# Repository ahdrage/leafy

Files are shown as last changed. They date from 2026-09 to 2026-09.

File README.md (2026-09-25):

# Leafy — DIY Wi-Fi Climate Controller for Nissan Leaf

**A DIY Nissan Leaf climate On/Off controller for home Wi-Fi.**

Leafy combines a custom ESP32-C3 board, a local web page and a printable enclosure. It requests climate operation over CAN; it does not carry or switch heater power. The intended profile is the **2013–2015 Leaf EV-CAN implementation**, subject to checking the actual vehicle and TCU configuration.

**Status: untested hardware prototype, Rev G.5 prepared for manufacture.** PCB production files and final component placement have been reviewed. Firmware builds and host tests pass, but no assembled Leafy has yet demonstrated heater control in a car. CAN transmission is disabled by default.

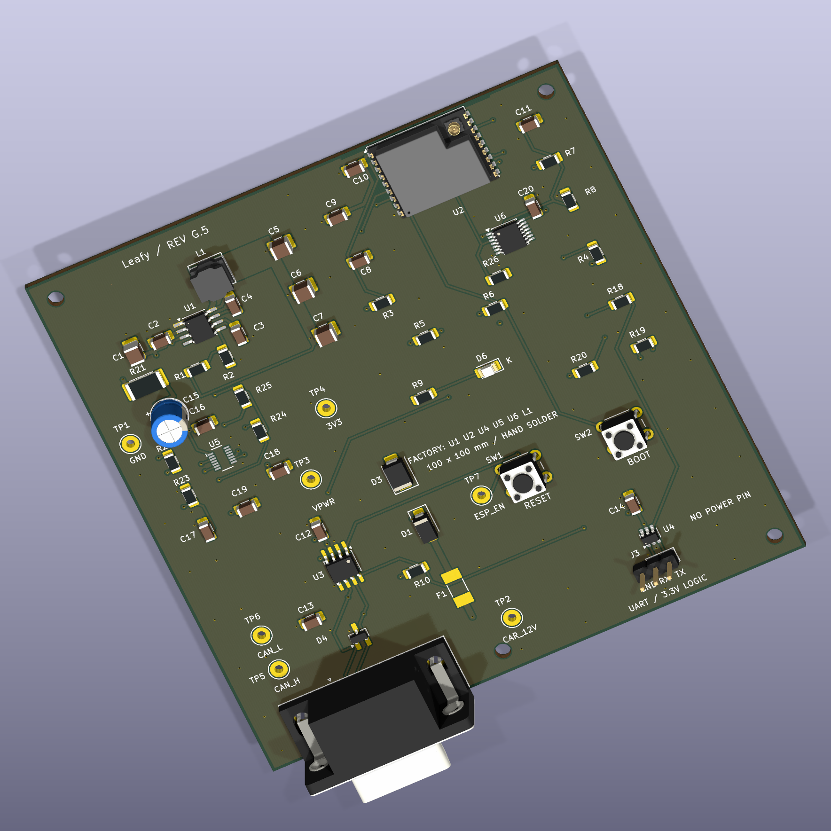
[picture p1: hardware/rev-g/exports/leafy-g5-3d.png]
Leafy G.5 PCB render


## Start here

| Goal | Documentation |
| --- | --- |
| Understand the project | [How it works](docs/OVERVIEW.md) |
| Build one | [Build guide](docs/BUILD-GUIDE.md) |
| Understand the decisions | [Development history](docs/DEVELOPMENT-HISTORY.md) |
| Inspect the current circuit | [G.5 design](hardware/rev-g/README.md), [schematic PDF](hardware/rev-g/exports/schematic.pdf), [KiCad project](hardware/rev-g/leaf-heat-v7.kicad_pro) |
| Buy components | [Parts and costs](docs/PARTS-AND-COSTS.md) |
| Order the PCB / partial assembly | [G.5 order guide](hardware/rev-g/ORDER-G5.md) |
| Build or test firmware | [Firmware instructions](firmware/leaf-heat/README.md) |
| Print the case | [Blender and STL files](enclosure/rev-g-v2/README.md) |
| Check the evidence | [Validation status](docs/VALIDATION.md) |

## Deliberately small scope

- **Heat on / Heat off** from a browser on the same home network.
- Wi-Fi only, external antenna, no SIM, subscription or cloud service.
- One CAN channel and the specified Nissan OVMS cable pinout.
- A 100 × 100 mm, four-layer PCB with generous hand-solder spacing.
- Factory assembly of **U1/U2/U4/U5/U6/L1**; **49 other components per board** are hand-soldered and the antenna plugs in.
- Independent low-battery cutoff, input damping and protected power/CAN interfaces.

Normal operation keeps Wi-Fi associated and retries after outages. **Battery protection cuts the board's power when voltage is too low**, so it becomes unreachable until the supply recovers. Availability also depends on the router and signal. Parked current and real-world reliability still need measurement.

The commands request the vehicle's climate function, not a particular heater element or temperature setpoint. The page reports requests, not independently verified heating.

## Thanks to OVMS

Leafy was inspired by the [Open Vehicle Monitoring System (OVMS)](https://www.openvehicles.com/). Its narrow Leaf wake-up and climate-command sequence is **derived from the OVMS Nissan Leaf implementation**, pinned to revision `85074a0ae7a983b308c6e2e081185492527ee073`.

Thank you to the OVMS authors and contributors for making this work available. The original MIT notice is retained in [OVMS-NOTICE.txt](firmware/leaf-heat/OVMS-NOTICE.txt). [Credits and provenance](CREDITS.md) explain the relationship and other sources. Leafy is an independent prototype, with no claimed OVMS or Nissan endorsement.

## Repository map

- `hardware/rev-g/`: current G.5 CAD, BOMs, manufacturing files, reviews and audit tools. The internal filename `leaf-heat-v7` is intentional.
- `firmware/leaf-heat/`: ESP-IDF firmware, settings template and 25 host tests.
- `enclosure/rev-g-v2/`: Blender source, STLs, renders and G.5 compatibility. Case renders retain their G.3 artwork provenance.
- `docs/`: project history, construction, costs, validation and publication notes.
- Earlier revisions and research: development history, **not current manufacturing instructions**. Always use matching G.5 files.

The public snapshot excludes personal supplier records, credentials, configured firmware images, downloaded toolchains and unrelated projects. Originals remain local. See [publication scope](docs/PUBLICATION.md).

## Licences

See [LICENSE.md](LICENSE.md) for the project licence boundaries and retained third-party notices.

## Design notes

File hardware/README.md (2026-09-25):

> **Historical development record.** The current release is [Leafy G.5](../README.md). Use this file for context, not current ordering or wiring instructions.

> **Rev A archive:** current manufacturing files are [Leafy Rev G.5](rev-g/README.md). All earlier revisions are preserved. The specifications below describe the obsolete two-layer Rev A.

# Leaf Heat — custom Wi-Fi board, Rev A

**Engineering prototype, not released for manufacture or vehicle installation.**

The native KiCad 10 project is [leaf-heat-v1.kicad_pro](leaf-heat-v1.kicad_pro). It contains an editable schematic and a fully routed, two-layer 65 × 50 mm PCB. There are 47 populated components and three mounting holes. The module antenna and the car connector extend beyond the PCB outline.

The design is for a small box with a local Wi-Fi page containing **Heat on** and **Heat off**. This delivery contains the hardware design, not working firmware. Home Wi-Fi coverage was confirmed by the owner. The earlier Waveshare development-board plan is an alternative prototype approach; its pin assignments must not be used for this PCB.

## Files

- [Schematic](leaf-heat-v1.kicad_sch) and [PCB](leaf-heat-v1.kicad_pcb)
- [Schematic preview](exports/leaf-heat-v1.svg) and [3D preview](exports/leaf-heat-v1-3d.png)
- [Complete component list](exports/BOM.csv), [grouped purchasing list](exports/BOM-grouped.csv) and [placement file](exports/placements.csv)
- Project-specific symbols in `Leaf.kicad_sym` and footprints in `Leaf.pretty/`; keep the two library tables alongside the project.
- `exports/fabrication-review/` contains Gerber copper, mask, silkscreen, paste and board-outline layers plus separate plated/non-plated drill files. These are for engineering/manufacturer review, not a production release.
- [Electrical check](exports/erc.json), [layout and schematic matching check](exports/drc-final.json), [design review notes](DESIGN-REVIEW.md), [tooling research](TOOLING.md).

## What is on the board

| Function | Main component | Reason |
|---|---|---|
| Wi-Fi and controller | Espressif ESP32-C3-WROOM-02-N4 | Integrated antenna, flash and crystal; native USB and one CAN controller |
| Car communication | TI TCAN3403DRQ1 | 3.3 V CAN interface with standby, plus PESD2CAN protection |
| Car power to 3.3 V | TI LMR36510ADDAR | 65 V-rated, 1 A buck regulator with light-load operation |
| Input protection | 1 A fuse, SS110, SMBJ24CA | Fuse, reverse blocking and transient suppression |
| Programming | USB-C, USBLC6-2SC6 | Program without a separate USB-to-serial adapter |
| Monitoring | Battery and USB voltage dividers | Firmware can monitor parked battery voltage and inhibit commands during bench work |

There is no cellular modem, SIM, display, SD card, relay or extra CAN channel. Most of the small parts are required for power conversion, protection, stable booting and programming. This board requests climate operation over the car's existing CAN network; it does not switch heater power.

The power circuit uses TI's 3.3 V / 400 kHz reference values: 22 µH, three 22 µF output capacitors, 100 kΩ / 43.2 kΩ feedback divider (about 3.315 V nominal). Component tolerances, capacitor DC bias and physical performance still need verification. See the [LMR36510 datasheet](https://www.ti.com/lit/ds/symlink/lmr36510.pdf).

## Cable and firmware connections

Use the **Nissan ZE0/e-NV200 OVMS cable**, after continuity-checking the actual cable. A generic OBD-to-DB9 cable is not interchangeable. At the board's male DB9: pin 9 = car +12 V, pin 3 = ground, pin 7 = CAN-H, pin 2 = CAN-L. The shell is grounded. No 120 Ω termination is fitted, because this is a connection to the car's existing terminated bus. Verify the vehicle's model year and EV-CAN access before connection; registration in 2015 alone does not prove a 2015 model year. [OVMS Leaf documentation](https://docs.openvehicles.com/en/latest/components/vehicle_nissanleaf/docs/index.html).

| Firmware signal | ESP32-C3 GPIO | Board behavior |
|---|---:|---|
| CAN TX | 4 | Connect to the internal TWAI controller |
| CAN RX | 5 | 500 kbit/s for the intended Leaf profile |
| CAN standby | 1 | Pulled high by R10; high = standby |
| Battery sense | 0 / ADC1 | `VPWR × 47 / 1047`; measured after D1, so calibrate the diode drop |
| USB presence | 3 / ADC1 | Half VBUS; detect with ADC and hysteresis, not a raw digital input threshold |
| Status LED | 7 | High lights the LED |
| USB D− / D+ | 18 / 19 | Native USB programming |
| Boot straps | 2, 8, 9 | Pulled high; BOOT button pulls GPIO9 low |

The intended firmware must start with CAN in standby, never replay a heat request after reset, implement a local stop deadline, handle bus errors, and use low-battery sleep. R17 discharges USB VBUS and D5 limits its rise from D2 leakage when the board is car-powered. USB and vehicle grounds are common; the board is not isolated. During initial programming and bench testing, disconnect the vehicle cable.

For the intended 2013–2015 profile, follow the documented OVMS TCU-disconnection requirement and verify the selected command sequence. Heater behavior, plugged/unplugged operation and shutdown must be observed on the actual car. Do not treat a successful CAN transmission as proof that the cabin is heating.

## Before a prototype order

Have the power circuit, connector land pattern and assembly choices reviewed. Confirm the exact DB9 part and cable mating arrangement, then request a quote for **an assembled prototype**, including the through-hole DB9 connector. The board contains an exposed-pad regulator and a radio module that need appropriate reflow assembly.

Proposed fabrication: two-layer FR-4, 1.6 mm thickness, 1 oz copper, lead-free finish, green mask, white silkscreen. The small routing escapes use 0.2 mm tracks; the project minimum is 0.15 mm clearance. Vias use 0.3 mm drills. The assembly provider must review paste apertures, thermal-pad via solder wicking, component orientation and panel handling around the overhanging antenna. Placement coordinates and Gerbers use the lower-left drill/place origin. J1 uses a footprint origin at signal pin 1, so its placement entry is not a component-body centroid.

The 3D image uses KiCad library models. The DB9 body model is approximate and must not be used to finalize an enclosure. No enclosure has been designed yet.

The first assembled board needs power, USB, standby-current, CAN and cold-temperature tests. The 65 V regulator and TVS do not by themselves establish automotive transient compliance. There is no hardware battery cutoff; unattended parked operation depends on tested firmware and measured current draw.

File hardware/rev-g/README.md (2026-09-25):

# Leafy — Rev G.5

**Current manufacturing revision: G.5.** The PCB now says **Leafy**. U1/U2 thermal holes require epoxy filling and copper capping, replacing G.4 mask tents. The new order uses Standard assembly and JLC normal stencil engineering. All components, wiring and mounting geometry remain compatible with the received Mouser parts.

Start with [the order guide](ORDER-G5.md), [change details](FILLED-G5-CHANGE.md), and [current packages](deliverables/README.md).

Rev G adds input damping and independent low-battery shutdown to the 100 × 100 mm, four-layer Wi-Fi/CAN board. It retains the hand-solder layout, Nissan DB9 cable interface and UART programming connector. **Rev F is preserved. This is a checked prototype design, not a vehicle-qualified product.**

- [Open in KiCad](leaf-heat-v7.kicad_pro), [schematic PDF](exports/schematic.pdf), [assembly image](exports/assembly-map.png)
- [Historical G.2 before/after images for Adi](review/leaf-heat-rev-g2-bilder-til-adi.zip)
- [Design review and remaining tests](DESIGN-REVIEW.md)
- [Factory instructions](MANUFACTURING-NOTES.md), [hand assembly](HAND-ASSEMBLY.md)
- [Exact hand-parts and antennas list for two boards](exports/MOUSER-TWO-BOARDS.csv), [verified basket and prices](MOUSER-SHOPPING.md)
- [Vehicle wiring](VEHICLE-WIRING.md), [firmware and programming](../../firmware/leaf-heat/README.md)
- [Updated Blender enclosure](../../enclosure/rev-g-v2/README.md)
- [Manufacturing/review packages](deliverables/README.md)
- [G.5 order guide](ORDER-G5.md), [complete order handoff](ORDER-HANDOFF-G5.json)

The factory now fits **U1, U2, U4, U5, U6 and L1**. U5 is the battery supervisor and U6 isolates the battery measurement when the 3.3 V supply is off; both have fine-pitch pins. You fit **49 other components per board**, using 27 different hand-parts products. The two-board shopping list contains 100 pieces: 98 soldered parts and two plug-in antennas, without spares. U3 and D4 still require careful hand soldering.

The important changes are:

- C15/R21 add a 47 µF / 63 V electrolytic capacitor with a separate 1 Ω damping resistor. The resistor is in the capacitor branch, not the board's main power path.
- U5 controls the regulator's enable pin independently of firmware. Nominal thresholds are approximately **11.67 V off / 12.68 V restart, measured after D1**, with nominal 1.27 s / 12.7 s delays. Actual thresholds and delays require measurement; see the review.
- U6 prevents the live battery divider from feeding an unpowered ESP32 ADC. The powered ADC conversion factor changes to **32.2766**.
- Regulator VCC and feedback routes shorten from 8.50 / 8.75 mm to 3.57 / 4.03 mm. Ground planes and antenna clearance are retained.
- The through-hole buttons change to C&K PTS645SL43-2 LFS, matching the contact geometry and 4.3 mm height.

The firmware is built around continuous Wi-Fi availability: station mode, modem sleep, automatic light sleep and unlimited reconnect attempts with a maximum 30-second retry interval. There is no intentional deep sleep or periodic offline schedule. Use the same non-isolated LAN and reserve the board's IP address in the router. **Low-battery cutoff necessarily makes the board unreachable until charging restores its supply.** Router outages, signal loss and firmware/hardware faults can also interrupt access.

Fresh ERC and DRC report zero errors, unconnected items or schematic mismatches under the configured rules. An independent script checks all 55 purchased components, critical pin connections, assembly ownership, unchanged cable/mount geometry and Rev F hashes. The firmware compiles, and its command/retry logic passes host tests. These checks do not establish real supply ripple, current consumption, RF performance or actual heater behavior.

The user has received the Mouser components. G.5 requires no changes to these parts or quantities; recorded basket exports remain available in the shopping notes. The first G.5 Standard order has reached PCB-file and final-placement review. See the public development history and cost record. Every future order still needs its own review. Before vehicle use, complete the documented bench plan and cable/TCU checks.

## Public project status

The G.5 PCB production files and final six-part assembly placement were reviewed on 25 September 2026. See the current [development history](../../docs/DEVELOPMENT-HISTORY.md) and [validation status](../../docs/VALIDATION.md); earlier order-preparation statements in this document are historical. Physical testing remains outstanding.

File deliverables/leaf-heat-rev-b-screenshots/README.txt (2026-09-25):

Leaf Heat Rev B — images for review

These images are rendered from the checked KiCad files; they are CAD exports, not photographs or fabricated UI screenshots. The board is an untested engineering prototype.

01: placement
02: top copper
03: dedicated GND plane
04: internal power/GND
05: bottom copper
06: USB route
07: USB-C and protection, top
08: USB-C local bridges, bottom (not mirrored)
09: regulator placement/routing
10: schematic

The 90 ohm USB impedance target still requires manufacturer stackup confirmation. No order has been placed for Rev B.

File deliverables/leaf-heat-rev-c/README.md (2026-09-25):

# Leaf Heat — Rev C

**Current custom-board revision: UART programming, 41 components, four layers, 65 × 50 mm. Engineering prototype; not physically tested.**

Open [leaf-heat-v3.kicad_pro](leaf-heat-v3.kicad_pro) in KiCad 10, then open PCB Editor or Schematic Editor. Rev B is preserved in `../rev-b/`.

The board receives heater commands over home Wi-Fi and communicates with the Leaf over CAN. It carries no heater current. Firmware, a verified vehicle cable, an enclosure, and prototype testing are still required.

## What changed

- Replaced USB-C programming with **J3, a three-pin serial programming header**. Pin 1 is ground, pin 2 receives data from the adapter, and pin 3 sends data to the adapter.
- Removed USB power input, USB voltage detection, CC resistors, USB data resistors and their unused wiring/copper.
- Retained ESD protection, repurposed for the UART lines. Added two 1 kΩ series resistors and a 10 kΩ receive-line pull-up. These resistor types already exist in the BOM.
- Retained RESET and BOOT buttons, the protected vehicle power input, the CAN circuit, the antenna clearance, the ground plane and the mounting-hole positions.
- **No controlled-impedance service is required for Rev C.** Use the standard four-layer construction described in [manufacturing notes](MANUFACTURING-NOTES.md).

There are **41 parts / 25 distinct MPNs**, compared with Rev B's 47 / 29. All components are on top: 39 SMT and two through-hole connectors. The connector must be included in factory assembly.

Programming now needs a **3.3 V logic USB-to-UART adapter and a separate 12 V bench supply**, connected through J1. J3 has no power pin. Follow the [programming instructions](PROGRAMMING.md); do not use a 5 V logic or RS-232 adapter.

## Verification and files

Native KiCad electrical and layout checks pass with zero reported violations, unconnected items and schematic/PCB mismatches. A separate saved-file audit checks the pin map, preserved circuit connections, copper net assignments, power tolerances and BOM/placement consistency. The [design review](DESIGN-REVIEW.md) records the scope, one documented KiCad check limitation and the remaining physical tests. Passing CAD checks does not establish a working or automotive-qualified product.

- [3D preview](exports/board-3d.png), [schematic](exports/schematic.png), [programming circuit](exports/programming-schematic.png)
- [Top copper](exports/top.png), [ground plane](exports/ground.png), [power distribution](exports/power.png), [bottom copper](exports/bottom.png), [assembly drawing](exports/placement.png)
- [PCBWay BOM](exports/BOM-PCBWay.csv), [JLCPCB BOM](exports/BOM-JLCPCB.csv), [placement coordinates](exports/placements.csv), [JLCPCB placement file](exports/CPL-JLCPCB.csv)
- [Electrical check](exports/erc.json), [layout check](exports/drc-final.json), [independent audit](exports/independent-audit.json), [manufacturing audit](exports/manufacturing-audit.json)

The native project, `.kicad_dru`, `Leaf.kicad_sym`, `Leaf.pretty/` and both library tables belong together. The Gerbers in `exports/fabrication/` are for Rev C only. Existing PCBWay/JLCPCB quotation requests contain **Rev B**, so their files and totals must not be treated as Rev C quotes.

## Firmware connections

| Function | ESP32-C3 GPIO | Behavior |
|---|---:|---|
| CAN transmit / receive | 4 / 5 | Internal TWAI controller |
| CAN standby | 1 | High = standby; external pull-up retained |
| Battery sense | 0 | ADC reads VPWR × 47/1047 after the input diode |
| Status LED | 7 | High lights LED |
| UART receive / transmit | 20 / 21 | Bootloader download and serial log |
| Reset / enable | EN | RESET button and 10 kΩ / 1 µF startup network |
| Boot straps | 2, 8, 9 | Pulled high; BOOT pulls GPIO9 low |
| Unused former USB pins | 3, 18, 19 | Explicit no-connect; no USB-presence detection |

Start with CAN in standby, require a fresh authenticated heat request after every reset, and implement a bounded heating interval, explicit stop handling, bus-error handling and low-battery behavior. Wi-Fi updates and recovery/rollback must be implemented in firmware; they are not provided by this hardware revision. The earlier development-board plan uses different GPIO assignments.

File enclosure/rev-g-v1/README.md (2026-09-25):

# Leaf Rev G enclosure v1

**G.2 compatibility:** the outline, mounting holes, all component/pad positions and 3D models remain unchanged from G.1. The existing case geometry is therefore compatible with G.2; see [the comparison](compatibility-g2.json). Original Blender renders show the earlier copper/silkscreen and retain their original hashes. This does not establish physical fit or environmental qualification.

Updated Blender case for the **100 × 100 mm Rev G PCB**, including the new radial capacitor and supervisor. The case keeps the Rev F dimensions and mounting pattern; its board reference, renders and validation now use Rev G.

- [Editable Blender file](leaf-rev-g-enclosure.blend)
- [Base STL](print/leaf-rev-g-case-base.stl), [lid STL](print/leaf-rev-g-case-lid.stl)
- [Closed view](previews/01-closed-case.png), [open view](previews/02-open-case-with-board.png), [exploded view](previews/03-exploded-case.png)
- [Fit/mesh checks](validation.json), [dimensions](parameters.json), [complete ZIP](leaf-rev-g-enclosure-package.zip)

Outside dimensions are **124.8 × 129.4 × 39.6 mm**. The tall floor standoffs retain access/clearance for the DB9 connector. PCB underside is at 18.4 mm, top at 20 mm and lid underside at 37.2 mm. C15's 11.2 mm body fits with approximately **6 mm vertical clearance**. The DB9/cable opening remains 42 mm wide. Actual cable hood and screwlock projection still need a physical fit test.

Only the supplied STL files are printable. The PCB, parts, screws and nuts in Blender are reference objects. Select `LID ASSEMBLY` and set its Z position to 0 mm to close the model, or 62 mm for the exploded view. Dimensions and STL coordinates are millimetres. Do not scale the parts in the slicer.

Print the base flat down and the supplied lid exterior-face down. Start with a 0.4 mm nozzle, 0.2 mm layers, at least four walls and adequate top/bottom layers. PETG can suit a supervised indoor/cabin fit prototype; select a filament with a documented heat rating appropriate to the final parked-car environment. Plain PLA is unsuitable for assuming hot-car durability. No temperature, flammability, condensation, vibration or weatherproof rating is claimed.

Bought fasteners (not included in the electronic-parts basket): four **unfilled nylon M2.5 × 8 mm screws and M2.5 nuts** for the PCB, and four **M3 × 10 mm screws and M3 nuts** for the lid. Test the actual screws/nuts with `print/OPTIONAL-fastener-fit-test.stl` before printing both case parts. Use `OPTIONAL-connector-fit-test.stl` to check the actual cable hood. Avoid metal PCB fasteners around the ESP32 antenna.

The four native PCB mounting holes align with the posts. Checks find manifold single solids, positive volume, correct millimetre-scale STL bounds, no base/lid intersection and no detected component/case surface collisions. C15 and U5 use conservative dimensional proxies; the DB9 model is based on drawing envelopes. This is digital verification, not proof of printed fit. The H2 support lies within the suggested antenna clearance region, so keep nylon hardware and test Wi-Fi range in the assembled case.

Rebuild with Blender 5.2.1 LTS:

```sh
/Applications/Blender.app/Contents/MacOS/Blender --background --factory-startup --python-exit-code 1 --python enclosure/rev-g-v1/build_enclosure.py
```

The native board hash in `parameters.json`, `reference/board-geometry.json` and `validation.json` must agree with the current Rev G PCB. Rev F enclosure files remain unchanged.

## Rev G.1 compatibility

The U5 BOM substitution uses the same DYY14 package and changes no physical PCB geometry. The existing Blender/STL files remain valid. [Compatibility check](compatibility-g1.json) ties the current PCB hash to the original rendered board through the full native geometry-equivalence audit. Original render/mesh provenance is retained; no new physical fit test is implied.

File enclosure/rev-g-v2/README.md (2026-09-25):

> Leafy G.5 compatibility: board outline, mounting holes, connector positions and component bodies are unchanged. See [compatibility record](compatibility-g5.json). Existing enclosure renders show G.3 artwork; the PCB now says Leafy.

# Leaf Rev G.3 enclosure v2

Updated Blender case for the **100 × 100 mm Rev G.3 PCB**, including the new radial capacitor and supervisor. The case keeps the existing dimensions and mounting pattern, adds a 2.2 mm drop-in antenna-cable exit with matching lid-lip relief and a rounded internal tie saddle. The board reference and renders show the new 02U module.

- [Editable Blender file](leaf-rev-g-enclosure.blend)
- [Base STL](print/leaf-rev-g-case-base.stl), [lid STL](print/leaf-rev-g-case-lid.stl)
- [Closed view](previews/01-closed-case.png), [open view](previews/02-open-case-with-board.png), [exploded view](previews/03-exploded-case.png)
- [Fit/mesh checks](validation.json), [dimensions](parameters.json), [complete ZIP](leaf-rev-g-enclosure-package.zip)

Outside dimensions are **124.8 × 129.4 × 39.6 mm**. The tall floor standoffs retain access/clearance for the DB9 connector. PCB underside is at 18.4 mm, top at 20 mm and lid underside at 37.2 mm. C15's 11.2 mm body fits with approximately **6 mm vertical clearance**. The DB9/cable opening remains 42 mm wide. Actual cable hood and screwlock projection still need a physical fit test.

Only the supplied STL files are printable. The PCB, parts, screws and nuts in Blender are reference objects. Select `LID ASSEMBLY` and set its Z position to 0 mm to close the model, or 62 mm for the exploded view. Dimensions and STL coordinates are millimetres. Do not scale the parts in the slicer.

Print the base flat down and the supplied lid exterior-face down. Start with a 0.4 mm nozzle, 0.2 mm layers, at least four walls and adequate top/bottom layers. PETG can suit a supervised indoor/cabin fit prototype; select a filament with a documented heat rating appropriate to the final parked-car environment. Plain PLA is unsuitable for assuming hot-car durability. No temperature, flammability, condensation, vibration or weatherproof rating is claimed.

Bought fasteners (not included in the electronic-parts basket): four **unfilled nylon M2.5 × 8 mm screws and M2.5 nuts** for the PCB, and four **M3 × 10 mm screws and M3 nuts** for the lid. Test the actual screws/nuts with `print/OPTIONAL-fastener-fit-test.stl` before printing both case parts. Use `OPTIONAL-connector-fit-test.stl` to check the actual cable hood. Also supply one small 2.5 mm nylon cable tie per case; ordinary mechanical/soldering supplies remain outside the electronics basket.

The four native PCB mounting holes align with the posts. Checks find manifold single solids, positive volume, correct millimetre-scale STL bounds, no base/lid intersection and no detected component/case surface collisions. C15 and U5 use conservative dimensional proxies; the DB9 model is based on drawing envelopes. This is digital verification, not proof of printed fit. The antenna now mounts outside the casing. Test Wi-Fi range in the actual car; the empty socket shown in the render needs ANT1 attached before radio use.

Rebuild with Blender 5.2.1 LTS:

```sh
/Applications/Blender.app/Contents/MacOS/Blender --background --factory-startup --python-exit-code 1 --python enclosure/rev-g-v2/build_enclosure.py
```

The native board hash in `parameters.json`, `reference/board-geometry.json` and `validation.json` must agree with the current Rev G.3 PCB. Rev F enclosure files remain unchanged.

## Antenna cable assembly

Fit the 300 mm Molex 1461530300 with the lid removed and power disconnected. Press its MHF I / U.FL plug squarely onto U2. Leave a slack loop, then route the coax over the rounded saddle and into the drop-in notch. Pass a 2.5 mm nylon tie through the saddle slot and around the cable; retain it gently without crushing the 1.13 mm coax. Smooth printed edges. Check that the cable can rest in the exit without being pinched when the lid closes, and that a light external pull is taken by the saddle/tie, not U2. Stop and correct fit if either check fails. No specified pull strength is claimed.

Mount the flex antenna inside the car on suitable plastic away from metal; the antenna is outside this box, not outside the vehicle. The entire lead is 300 mm, including routing inside the case. Keep bend radii generous and avoid tension or tight folds. The casing is not waterproof.

## G.4 compatibility

The G.4 revision changes U1/U2 solder mask and paste only. All mounting/outline/component geometry remains unchanged and the enclosure is compatible; see [the verification record](compatibility-g4.json). Existing 3D files and renders retain G.3 provenance and have not been relabelled as G.4 renders.

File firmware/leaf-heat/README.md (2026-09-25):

# Rev G Leaf heat firmware

Buildable ESP32-C3 prototype for the **Rev G custom board, including the current G.5**. It serves a local Heat on/Off page and stays associated with the home Wi-Fi using modem sleep and automatic light sleep. It retries indefinitely at 1, 2, 4, 8, 16, then 30-second intervals. It does not use scheduled deep sleep, deliberately disconnect Wi-Fi, or replay Heat on after reconnect/reboot.

**CAN writing is disabled by default.** No firmware has been flashed or tested in the car. Successful compilation and host tests do not validate the CAN hardware, current draw or heater response.

For a fresh portable setup, see [the build guide](../../docs/BUILD-GUIDE.md). The commands below also document the original local tool layout.

## Configure, build and flash

1. Copy `include/settings.example.hpp` to `include/settings.hpp`. Enter the home's 2.4 GHz Wi-Fi SSID/password and a separate control key of at least 12 characters. Keep this local file private. The control key is entered on the web page and is not embedded in its HTML. Credentials are stored in the firmware image, so keep configured binaries private too.
2. Keep `LEAF_CAN_WRITE_ENABLED false` through assembly, supply/current checks and initial network commissioning. Set the ADC correction from meter measurements at VPWR. The nominal divider multiplier is **32.2765957447**, different from Rev F.
3. Build from the repository root:

   ```sh
   PLATFORMIO_CORE_DIR="$PWD/tools/platformio" tools/firmware-venv/bin/pio run -d firmware/leaf-heat
   ```

   The project pins PlatformIO Espressif32 **6.12.0**, with ESP-IDF. The bundled local environment has PlatformIO 6.1.18. A default build uses empty Wi-Fi credentials and therefore cannot join a network until configured; it is a compile-check image.
4. Power the fully assembled board from a current-limited 13.5–14 V bench supply through J1. Use a **3.3 V logic** UART adapter: TX → J3 pin 2/RX, RX → pin 3/TX, GND → pin 1. Leave the adapter's power lead insulated. Connect adapter only after board power is present; disconnect it before removing board power. There is no USB socket or UART power input.
5. Hold BOOT, press/release RESET, release BOOT. Run `pio run -d firmware/leaf-heat -t upload --upload-port /dev/cu.YOUR_ADAPTER` using the same `PLATFORMIO_CORE_DIR` and executable as above. Choose the actual adapter port, not a guessed one. The build generates the correct bootloader/partition/application offsets; do not flash the application alone at address zero.
6. Read the 115200-baud serial log for the IP address. Reserve that IP in the router and bookmark `http://ADDRESS/`. Hostname is `leaf-heat`, but `.local` discovery is not implemented. Both phone/computer and car must be on the same LAN without guest/client isolation. The page has no cloud or Internet dependencies.
7. Only after the wiring, TCU and bench CAN checks in the hardware guide pass, explicitly enable CAN writing, rebuild and flash. Test beside the car before relying on remote heating.

## Behavior and limits

The web page requires the configured key on every control request. Commands use a custom HTTP header, accept no request body and expose no CORS permission. HTTP is unencrypted: use only the trusted home LAN, with no port forwarding. This is not an Internet-facing service.

On wakes the 2013–2015 EV-CAN profile, sends 24 climate requests 100 ms apart and the OVMS completion frame at approximately 3.3 seconds. Off cancels an outstanding On sequence. The command queue retains at most one request; delayed On requests expire after one second. CAN remains in hardware standby while idle, and the TWAI driver is released to allow automatic light sleep. After taking the transceiver out of standby, firmware waits 100 µs before transmitting, independently of the scheduler's tick rate.

Transmissions use normal CAN arbitration/retries and require a bus acknowledgement. Each frame has a **40 ms transmit-result wait**; on timeout or a terminal error the firmware puts the transceiver in standby and stops/uninstalls the driver, cancelling any pending transmission. Scheduling delays can extend the time before this cancellation executes; this is not a hard real-time deadline. Off can preempt the remaining sequence once the current bounded send returns. A failed command is not automatically replayed. A CAN ACK is **not** a confirmation that the heater started.

A local 15-minute timer requests Off even if Wi-Fi is lost. A low/invalid voltage reading blocks On; low voltage during a heat request triggers an early Off attempt after 10 seconds. Every admitted On starts a fresh low-voltage interval and re-arms this protection, including an On whose wake transmission fails and leaves the outcome uncertain. Rejected requests do not reset it. A failed early Off is not repeatedly sent during the same low-voltage episode. U5 can cut power sooner in a deep voltage dip. Loss of power, failed CAN transmission, a reset, or the car ignoring a request can prevent Off. Confirm the car's own timeout and test these cases. The page reports requests and errors, never an invented actual heater state.

The cutoff protects the 12 V battery even if firmware hangs. It also makes Wi-Fi unavailable until charging restores the board's input above its recovery threshold. This exception is unavoidable for a battery-powered always-listening device. Actual connected and disconnected-router current must be measured.

## Verification

The host suite contains **25 behavioral tests**: 10 for the real command/retry core, six for the production battery/control task, and nine for the production CAN transport. The latter two compile verbatim functions extracted from `src/main.cpp` against simulated SDK boundaries. They exercise the actual task and transport decisions, but do not execute ESP-IDF itself or validate electrical behavior. The runner rejects missing or ambiguous source boundaries.

Coverage includes repeated heat sessions after partial battery recovery, an uncertain On following failed transmission, rejected requests, bounded CAN contention, missing ACK, bus-off, pending-frame cancellation, and standby timing at 100/1,000 Hz. Existing tests cover command timing, Off preemption, 100,000 capped Wi-Fi retries, no boot/idle replay, the local timeout and authentication.

`verification/review-fixes-red.txt` records seven behavioral failures before the fixes; `review-fixes-green.txt` records the final 25 passing tests. The original `host-red.txt`/`host-green.txt` remain historical records. `verification/build.log` records the normal ESP32-C3 commissioning build; `can-enabled-build.log` records a separate temporary compile/link check with CAN enabled and empty Wi-Fi credentials, without flashing. See [fix details and bench checks](verification/REVIEW-FIXES.md). The earlier `integration_contract.py` source-string experiment is retained as scratch work and is not behavioral test coverage or a release check.

```sh
python3 firmware/leaf-heat/tests/run_host_tests.py
```

Hardware SDK behavior was additionally inspected for TWAI queue requirements and power-management locks. There has been no device runtime, RF, CAN or vehicle test. Perform the [Rev G prototype test plan](../../hardware/rev-g/DESIGN-REVIEW.md).

Protocol source: [pinned OVMS implementation](https://github.com/openvehicles/Open-Vehicle-Monitoring-System-3/blob/85074a0ae7a983b308c6e2e081185492527ee073/vehicle/OVMS.V3/components/vehicle_nissanleaf/src/vehi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). See `OVMS-NOTICE.txt` for the upstream license. Power strategy follows [Espressif's sleep guidance](https://docs.espressif.com/projects/esp-idf/en/stable/esp32c3/api-reference/system/sleep_modes.html); modem sleep plus automatic light sleep maintains Wi-Fi association, whereas explicit sleep entry does not.

G.3 antenna compatibility: ESP32-C3-WROOM-02U-N4 retains the same GPIOs and 4 MB flash. No firmware code change is needed. Connect the specified external antenna before enabling Wi-Fi. All 25 host tests were rerun successfully after the hardware substitution; physical RF testing remains outstanding.

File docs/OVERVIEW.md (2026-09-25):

# How Leafy works

A browser on the home network sends an authenticated On/Off request to the ESP32-C3. The firmware sends the appropriate CAN sequence through the specified Nissan cable. The car must be within usable 2.4 GHz Wi-Fi range.

```mermaid
flowchart LR
    Browser[Browser: Heat on / off] --> WiFi[Home Wi-Fi and external antenna]
    WiFi --> MCU[ESP32-C3 / U2]
    MCU --> CAN[CAN transceiver / U3]
    CAN --> Cable[Nissan EV-CAN cable]
    Cable --> Car[Vehicle climate controller]
    Battery[12 V supply] --> Protection[Fuse, diode, TVS and damping]
    Protection --> Regulator[3.3 V regulator / U1]
    Regulator --> MCU
    Protection --> Supervisor[Battery supervisor / U5]
    Supervisor -->|enable / shutdown| Regulator
```

| Block | Role |
| --- | --- |
| U1 / L1 | Convert vehicle power to 3.3 V; exposed-pad regulator and 22 µH inductor |
| F1 / D1 / D3 / C15 / R21 | Fuse, reverse blocking, transient clamp and input damping; real transient performance remains untested |
| U2 | ESP32-C3-WROOM-02U-N4, Wi-Fi MCU with external antenna socket |
| U3 | TCAN3404DRQ1 CAN transceiver, fixed to EV-CAN; no selectable second bus or extra board termination |
| U5 | Independent low-battery cutoff, even if firmware hangs |
| U6 | Disconnects the live battery divider from the unpowered processor ADC |
| U4 / J3 | Protected 3.3 V serial programming; no on-board USB socket or power input |

Nominal cutoff/restart is about **11.67/12.68 V at VPWR after the diode**, with delays and tolerances in the design review. These are calculations, not measured battery-terminal thresholds. The antenna's 300 mm lead permits mounting outside the enclosure, on plastic inside the car; improved range is not yet measured.

The page requires a separate control key and uses ordinary HTTP on a trusted LAN. There is no cloud service, mDNS or OTA update implementation. Reserve the board's IP address in the router; do not use port forwarding. Router guest/client isolation can prevent access.

Reconnect retries are unlimited with a 30-second cap. Reboot/reconnect does not replay old On requests. CAN stays in standby while idle. The sequencer supports Off preemption, bounded transmit waits and a local 15-minute Off timer. A CAN acknowledgement is not proof that climate started. Loss of board power or bus communication can prevent Off; check the car's own timeout.

This prototype does not provide cellular access, diagnostics, charging control, door locking, temperature setting or support for every Leaf generation. No automotive, EMC, ingress or environmental qualification is claimed.

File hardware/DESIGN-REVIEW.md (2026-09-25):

> **Rev A archive:** the current four-layer layout and review are in [rev-b/README.md](rev-b/README.md). The specifications below describe the preserved two-layer Rev A.

# Rev A design review and validation record

Date: 2026-09-11. Tool: KiCad 10.0.6.

## Completed checks

- Native KiCad schematic electrical rules check: **0 violations**.
- Native KiCad PCB rules check with filled ground zones: **0 violations**.
- Native KiCad unconnected-items check: **0 remaining connections**.
- Native KiCad PCB-to-schematic comparison: **0 mismatches**.
- No DRC exclusions were used to hide routing errors. Power-source flags identify external supplies and the regulator output in the schematic.
- The PCB was populated from the schematic's exported netlist. Manufacturer and MPN fields were copied into the footprints. The three mechanical holes are marked board-only and excluded from purchasing/placement lists.
- Power-switching and USB connections were routed explicitly. Remaining connections were routed locally, then native KiCad findings were corrected. Both copper layers contain ground pours; the radio antenna keepout is retained.
- Native 2D and 3D views were inspected. The design was opened in the user's KiCad application.

These checks establish CAD connectivity and geometry under the configured rules. They do not validate the circuit under load, radio performance, firmware, CAN behavior or compatibility with the actual vehicle.

## Custom library review

- `NorComp_182-009-113R531`: signal spacing 2.77 × 2.84 mm; 1.20 mm signal drills; mounting pitch 24.99 mm; mounting drills 3.20 mm. Based on the manufacturer's [182-series drawing](https://content.norcomp.net/rohspdfs/Connectors/18Y/182/182-yyy-113Ryy1.pdf). The generic body model/outline is approximate. Confirm the exact hardware suffix, connector mating depth and enclosure setback before releasing the board.
- `ESP32-C3-WROOM-02_0p3mm_Vias`: derived from KiCad's module footprint. Ground-pad thermal holes are 0.30 mm with 0.65 mm pads instead of the library's 0.20 mm holes. The antenna keepout remains in place. Printed outline segments are clipped to the PCB edge; the antenna intentionally overhangs.
- The custom TCAN3403 and USBLC6 symbols are simplified functional symbols with pin numbering taken from their manufacturer datasheets. The USBLC6 drawing represents the ESD array as a block, not its internal semiconductor circuit.

## Pending engineering and physical verification

1. Review the supply layout against TI's layout recommendations, including the input loop, switch node, feedback routing, capacitor effective capacitance, inductor temperature/current margin and exposed-pad assembly. The board has not been simulated or measured.
2. Confirm component availability and substitutes in the chosen assembler's quote. Do not silently replace the regulator variant, radio module, connector or protection parts. The part list is a design BOM, not a live stock reservation.
3. Measure 3.3 V during USB startup and Wi-Fi transmit bursts at the minimum intended USB voltage, and from a current-limited 12–14.5 V bench source. Check regulator temperature, ripple, restart and diode reverse leakage over temperature. USB power is intended for bench programming; do not assume every long or low-quality cable can start it reliably.
4. Verify that absent USB does not register as present, and that USB-present detection uses ADC thresholds. The 100 kΩ/100 kΩ divider gives approximately 2.5 V from 5 V VBUS, which is too close to the guaranteed digital-high threshold to rely on digital input sensing across tolerances.
5. Measure sleep and Wi-Fi connected current at the car input. Firmware must set a conservative low-battery threshold and avoid a rapid wake/sleep cycle. Determine the actual maintenance burden on the Leaf's 12 V battery before leaving the device connected.
6. Check the passive cable with a meter, establish the vehicle's model-year profile, and follow OVMS instructions for the original TCU. Start with CAN listen-only tests and observe bus health before enabling heat commands. Verify standby across reset, firmware updates and USB connection.
7. Test heat-on, heat-off, the local stop timer, reboot during heating, Wi-Fi loss, charger-connected and charger-disconnected behavior. Confirm no continued bus wakefulness after the command sequence finishes.
8. Review the proposed input-transient envelope and test it with suitable equipment. SMBJ24CA has finite pulse-energy capacity. There is no claim of ISO 7637 or ISO 16750 compliance, EMC approval or completed automotive qualification.
9. Fit-test the connector and mounting holes; design a non-metallic enclosure that keeps the antenna clear of wiring and metal. Verify condensation, cold operation, cable strain relief and retention before installation.

## Primary design references

- [OVMS Nissan Leaf integration](https://docs.openvehicles.com/en/latest/components/vehicle_nissanleaf/docs/index.html)
- [TI LMR36510 power regulator](https://www.ti.com/lit/ds/symlink/lmr36510.pdf)
- [TI TCAN3403-Q1 CAN transceiver](https://www.ti.com/lit/gpn/TCAN3403-Q1)
- [Espressif ESP32-C3-WROOM-02 module](https://documentation.espressif.com/esp32-c3-wroom-02_datasheet_en.html)
- [Espressif schematic checklist](https://docs.espressif.com/projects/esp-hardware-design-guidelines/en/latest/esp32c3/schematic-checklist.html)
- [Bourns SRN6045TA inductor](https://www.bourns.com/docs/Product-Datasheets/SRN6045TA.pdf)
- [Nexperia PESD2CAN](https://assets.nexperia.com/documents/data-sheet/PESD2CAN.pdf)
- [Nexperia PMEG6030EP](https://assets.nexperia.com/documents/data-sheet/PMEG6030EP_.pdf)
- [Nexperia BZT52-B Zener series](https://assets.nexperia.com/documents/data-sheet/BZT52-B_SER.pdf)
- [ST USBLC6-2](https://www.st.com/resource/en/datasheet/usblc6-2.pdf)
- [GCT USB4105 connector](https://gct.co/files/drawings/usb4105.pdf)
- [NorComp 182 connector](https://content.norcomp.net/rohspdfs/Connectors/18Y/182/182-yyy-113Ryy1.pdf)

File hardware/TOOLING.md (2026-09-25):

# KiCad tooling choice

The requested [KiCAD-MCP-Server](https://github.com/mixelpixx/KiCAD-MCP-Server) was installed locally at `../tools/KiCAD-MCP-Server`, version 2.7.0, commit `ac716d1a8bfad325b4aa93a398222645b3f78fd7`.

Its Node dependencies and TypeScript server were built, and its Python dependencies were installed into a project virtual environment using KiCad's bundled Python 3.9. The MCP server was exercised over local standard input/output and used to create the native project. `../tools/kicad-call.mjs` is the local MCP client wrapper. This is a working local installation, not a globally registered Codex plugin or an exposed network service.

For this design, the most reliable tested workflow was a combination of the MCP server, native KiCad libraries/Python bindings, native command-line validation and GUI inspection. Native KiCad ERC and DRC were the final authority. The server's early-start Python readiness race required a limited retry in the local client. TypeScript compilation was restricted to the server's own type directories to avoid unrelated parent-directory packages.

The repository now points to [Konnect](https://github.com/mixelpixx/Konnect), its newer native-IPC successor with KiCad 10/macOS support. It was researched but not installed. There was no need to replace the working toolchain mid-design. This is a recommendation based on the setup tested here, not a comparative benchmark of every KiCad automation tool. KiCad's API transition is documented in the [official API overview](https://dev-docs.kicad.org/en/apis-and-binding/index.html).

Routing ran locally with [Freerouting](https://github.com/freerouting/freerouting) 2.4.1 and a portable Temurin Java 25 runtime. Analytics and its API server were disabled for routing. No board was uploaded to a cloud autorouter. Both downloaded archives were checked against the release-provider SHA-256 values:

- Freerouting JAR: `251101c3eeac22d7e7dfcf6796603279e5d1000283eb82d8f093780f7afc6aa9`
- Temurin JRE archive: `5b02bcc908da092e7e00b9772d4f9bbb87f44a60b7c90f7cf5a91a1d98f37e1b`

The root `hardware/*.py` files record the generation and routing iterations. The checked native CAD files are the deliverable; these scripts are not a supported one-click regeneration pipeline and may overwrite manual work. Use KiCad for subsequent edits and rerun ERC/DRC and manufacturing exports afterward. The local MCP installation is not required merely to open or edit the project.

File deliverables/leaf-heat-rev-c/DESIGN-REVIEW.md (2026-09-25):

# Rev C design review — 12 September 2026

**The USB-removal revision is complete and passes the documented CAD checks. It is not yet a demonstrated working heater controller.** Physical power, flashing, CAN, parked-current and vehicle tests cannot be established from CAD files.

## Change and cost rationale

The schematic and PCB replace USB-C with a UART0 programming header. Ten components were removed: J2, D2, D5 and R11–R17. Four were added: J3 and R18–R20. U4 was rewired as UART ESD protection; C14 changed from 1 µF to 100 nF and moved with it. U2 now uses GPIO20/21 for UART, while GPIO3/18/19 are no-connects. All other electrical connections, values and MPNs were compared against Rev B.

Population falls from **47 to 41** and distinct MPNs from **29 to 25**. The custom PCB has no USB differential pair and can use a standard four-layer stack without paid impedance control. Earlier calculator comparisons showed a $50.20 PCBWay fabrication difference and a $32.84 JLCPCB charge for the Rev B impedance option, **per batch**. These are evidence of removable service costs, not a fresh Rev C quotation or guaranteed net saving. The external programmer, bench supply/lead, connector assembly and current component sourcing also affect total cost. Existing online quotation requests still refer to Rev B.

Four layers and 1 oz inner copper remain. Reducing layer count, copper thickness or changing the vehicle interface would be separate work and is unnecessary to remove the USB-related charge.

## Electrical review

**Programming.** J3 pin 1 is GND, pin 2 is board RX and pin 3 is board TX. The saved schematic and pad map were checked against U2's module pins 11 (GPIO20/RXD) and 12 (GPIO21/TXD). RESET and the GPIO9 BOOT button remain, as do the high straps on GPIO2 and GPIO8. Serial recovery therefore remains available independently of application firmware. [ESP32-C3 module datasheet](https://documentation.espressif.com/esp32-c3-wroom-02_datasheet_en.html), [download guidance](https://docs.espressif.com/projects/esp-hardware-design-guidelines/en/latest/esp32c3/download-guidelines.html).

R18 and R19 are 1 kΩ series resistors, using the existing LED-resistor MPN. R20 is an existing-type 10 kΩ pull-up so RX does not float. Espressif recommends series resistance on UART TX, with 499 Ω as its example. Our 1 kΩ choice is an engineering tradeoff for part consolidation and current limiting at 115200 baud. With an assumed total 100 pF cable/input load, estimated 10–90% edge time is 0.222 µs, versus an 8.68 µs bit. With a 0.4 V adapter low, worst 1% resistor corners and supply corners, RX is approximately 0.679 V, below the conservative 0.805 V low threshold. These calculations do not qualify arbitrary cables or faster flashing. [Espressif schematic guidance](https://docs.espressif.com/projects/esp-hardware-design-guidelines/en/latest/esp32c3/schematic-checklist.html).

**ESD.** U4 has two feed-through channels: pins 1/6 protect RX and 3/4 protect TX; pin 2 returns to GND and pin 5 references the 3.3 V rail. C14 is a local 100 nF bypass. Protection sits near the service connector, with two nearby ground vias. The part is usable for signal protection beyond USB; it does not implement a USB protocol. Its presence does not establish whole-board ESD immunity. Connect only a 3.3 V logic adapter to a powered board; the resistors are not level shifters, and this interface does not provide powered-off isolation. [ST USBLC6-2 datasheet](https://www.st.com/resource/en/datasheet/usblc6-2.pdf).

**Power.** The board is powered through J1 pin 9, F1 and D1 into VPWR. The USB diode-OR branch and its leakage/discharge network are gone. J3 exposes no 5 V, 3.3 V or 12 V supply pin. The buck retains TI's 3.3 V reference values: 22 µH, three 22 µF output capacitors, 2.2 µF + 220 nF input capacitors, 100 kΩ/43.2 kΩ feedback, 1 µF VCC and 100 nF bootstrap bypass. Nominal output is 3.315 V; static corners using ±1.5% reference and 1% resistors are 3.220–3.412 V, within both major ICs' supply ranges. Ripple, DC-bias-dependent capacitance, startup and load transients still require measurements. The regulator pinout, capacitor voltage ratings and inductor MPN were retained and checked against the datasheet guidance. [TI LMR36510 datasheet, tables 6.5 and 8.1](https://www.ti.com/lit/ds/symlink/lmr36510.pdf).

**CAN and car input.** The fuse, reverse-blocking diode, input TVS, TCAN3403 and PESD2CAN network retain their connections and placement. U3 pins 3 and 5 use 3.3 V; pin 8 has standby pull-up R10. TX/RX remain GPIO4/5 and standby GPIO1. The DB9 remains pin 9 power, 3 ground, 7 CAN-H, 2 CAN-L. No bus termination or common-mode choke was added. U3's component-level ±58 V bus rating is not a whole-board transient test result; the TVS and input protection also have finite ratings. [TI TCAN3403-Q1 datasheet](https://www.ti.com/lit/gpn/TCAN3403-Q1), [PESD2CAN datasheet](https://assets.nexperia.com/documents/data-sheet/PESD2CAN.pdf).

The battery divider remains after D1 and needs calibration for diode drop. Its worst 1% corner is 2.974 V at 65 V VPWR; normal 12 V operation is far lower. This arithmetic does not rate the entire board for a sustained 65 V input: the input TVS conducts far below that. There is no independent hardware battery cutoff.

## Layout, mechanics and assembly

The saved board has a dedicated In1.Cu ground plane with no routed tracks. In2.Cu distributes 3.3 V and GND; its 3.3 V area extends to the UART protection. Both internal layers remain free of tracks. There are 84 separate ground vias, excluding thermal holes inside footprints. The new UART routes use F.Cu and B.Cu; they require no differential length/impedance rule. The protection chip sits immediately above J3, with approximately 3 mm of copper between each header signal and its ESD contact.

The original power/CAN placement and surviving route geometry were compared by footprint and copper-item identifiers. All 278 surviving original copper items retain their net assignments and endpoints. Obsolete USB copper and obstructing ground vias were removed deliberately; replacement local returns were added. Ground under the top UART routing was sampled at intervals no greater than 0.1 mm. The only absent-ground samples are expected non-ground plated-hole clearances. The antenna keepout remains on all copper layers and was checked against filled copper.

J3's 2.54 mm pitch, three 1.00 mm holes, pin-one marking and top mounting were checked against the saved board and [Harwin's connector specifications](https://www.harwin.com/products/M20-9990346). Its ground pin has thermal reliefs. It is not keyed; the three contacts are clearly printed. The existing DB9 footprint and mounting holes remain; its library 3D body is approximate. Physical mating and enclosure clearance still need confirming with the actual cable and connector. The J1 schematic symbol now explicitly names the custom footprint in its filter; its electrical pin map did not change.

All 41 placement rows match saved PCB coordinates and rotations, with no missing or extra components. The BOM identifies 39 SMT parts and two THT connectors. Gerber/drill origins and four copper-layer exports were checked. J1/J3 origins are pin 1, so their centroid/rotation interpretation must be reviewed by the assembler. Exposed-pad stencil and thermal-hole solder wicking also require factory process review.

## Check results and limits

| Check | Result |
|---|---|
| Native KiCad 10.0.6 ERC | 0 reported violations |
| Native DRC after zone refill, all reported severities and all track errors | 0 reported violations |
| Unconnected items | 0 |
| Schematic/PCB parity | 0 mismatches |
| Explicit DRC exclusions | None |
| Independent schematic/pad/BOM/preserved-copper audit | Passed |
| Placement count/origin/rotation audit | 41/41 passed |
| Visual review | Schematic, UART circuit, all four copper layers, placement and 3D rendering reviewed |
| Physical tests / firmware / car operation | Not performed / not implemented |

The footprint-type heuristic remains disabled because KiCad classified U1's SMD footprint as through-hole based on its plated thermal holes. U1 and U2 are correctly declared and purchased as SMT parts. The diagnostic result is preserved in `exports/drc-expanded.json`; this is a documented checker limitation, not a concealed electrical failure. Missing-courtyard, footprint-filter and track-to-via alignment checks that were disabled in Rev B are enabled in Rev C. The unused tuning-profile check remains disabled. ERC's inherited non-applicable simulation/global-label settings are listed in its report.

Evidence: [ERC](exports/erc.json), [DRC](exports/drc-final.json), [independent audit](exports/independent-audit.json), [manufacturing audit](exports/manufacturing-audit.json), [Rev B hashes](exports/baseline-sha256.json). The audit is not an independent human engineering sign-off or a substitute for a prototype.

## First prototype acceptance

1. Factory checks exact parts, polarized orientations, connector fit, stencil/thermal-hole treatment and complete assembly. Review its placement preview before production.
2. On a disconnected bench, inspect joints and check power-to-ground resistance before applying a current-limited 12 V supply. Measure 3.3 V and supply current, then exercise expected load and Wi-Fi bursts while checking ripple, reset behavior and regulator temperature.
3. Confirm UART boot log, first flash, normal reset and recovery after an intentionally nonworking application. Use 115200 baud and verify clean signal levels with the chosen lead.
4. Test CAN standby through power-up/reset, communication against a known CAN test setup, error handling and restart behavior. No vehicle connection is needed for these first tests.
5. Implement and verify firmware: authenticated local requests, no replay after boot, bounded heating/stop behavior, Wi-Fi reconnection and measured parked-current/low-battery policy. There is no USB-presence inhibit anymore; initial development stays on the disconnected bench. OTA/rollback is separate firmware work.
6. Verify the actual Nissan ZE0 cable pinout and the car's model-year/TCU requirements, then observe heat-on and heat-off on the car under supervision. Test plugged/unplugged behavior and bus sleep before leaving the box installed. Registration year alone is not a verified protocol profile. [OVMS Nissan Leaf documentation](https://docs.openvehicles.com/en/latest/components/vehicle_nissanleaf/docs/index.html).

Automotive transient, EMC/EMI and cold-temperature operation remain unqualified. This review preserves the agreed existing vehicle-protection design; it does not certify it or claim that every possible vehicle fault is covered.

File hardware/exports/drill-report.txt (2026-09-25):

Drill report for leaf-heat-v1.kicad_pcb
Created on 2026-09-11T22:25:59

Copper Layer Stackup:
    =============================================================
    L1 :  F.Cu                      front
    L2 :  B.Cu                      back

Drill file 'leaf-heat-v1-PTH.drl' contains
    plated through holes:
    =============================================================
    T1  0.300mm  0.0118"  (52 holes))
    T2  0.300mm  0.0118"  (12 holes))
    T3  0.330mm  0.0130"  (6 holes))
    T4  0.600mm  0.0236"  (4 holes)  (with 4 slots)
    T5  1.200mm  0.0472"  (9 holes))
    T6  3.200mm  0.1260"  (2 holes))

    Total plated holes count 85

Drill file 'leaf-heat-v1-NPTH.drl' contains
    unplated through holes:
    =============================================================
    T1  0.650mm  0.0256"  (2 holes))
    T2  2.700mm  0.1063"  (3 holes))

    Total unplated holes count 5

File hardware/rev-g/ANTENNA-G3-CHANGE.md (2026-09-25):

# Rev G.3 — external Wi-Fi antenna

U2 changes from Espressif ESP32-C3-WROOM-02-N4 to **ESP32-C3-WROOM-02U-N4**, factory supplied by JLCPCB as **C2926676**. ANT1 is one **Molex 1461530300** per board, ordered from Mouser as **538-146153-0300** (supplier MPN punctuation: 146153-0300). It plugs directly into U2's U.FL socket; no extra adapter or RF trace is needed.

The antenna has an integral 300 mm, 1.13 mm coax cable and an MHF I / U.FL compatible plug. Its adhesive flex element is approximately 35 × 9 mm. At the board's 2.4 GHz operating band it is specified as 50 Ω, 2.2 dBi peak gain, with operating temperature −40 to +85 °C. The extra 5/6 GHz bands do not add 5 GHz capability to this ESP32-C3.

Sources checked 14 September 2026:

- [Espressif module datasheet](https://documentation.espressif.com/esp32-c3-wroom-02_datasheet_en.html), external antenna connector and recommended land patterns. A PDF is saved in `references/esp32-c3-wroom-02-02u.pdf`.
- [Molex specification F3](https://www.molex.com/content/dam/molex/molex-dot-com/products/automated/en-us/productspecificationpdf/146/146153/PS-146153-100-001.pdf), §3 (MHF I for 0XXX, 300 mm, temperature), §6.1.6 (2.4 GHz gain). The current product specification supersedes older brochure temperature figures. Direct PDF download failed; the online PDF was inspected.
- [JLCPCB's Espressif catalogue entry](https://jlcpcb.com/partdetail/3250151-ESP32_C3_WROOM_02UN4/C2926676). Avoid the similarly named generic assembly-service entry.

## Electrical and manufacturing changes

Both module variants have the same 19 numbered pins, GPIO functions and 4 MB flash. The official KiCad land patterns compare identically. The new body is 18 × 14.3 mm instead of 18 × 20 mm. The local symbol description, MPN, schematic, PCB footprint outline, 3D model and factory BOM now identify the external-antenna version.

All traces, vias, filled copper, pad positions, pad sizes, drill sizes, paste apertures, board edges and mounting holes remain identical to G.2. The old module's antenna keepout is deliberately retained as unused clearance; it causes no loss of function. No RF signal is exposed as a fabricated PCB pin. The schematic documents ANT1 as an off-board plug-in accessory, and `accessories.json` / `BOM-ACCESSORIES.csv` track it separately.

The factory still fits exactly U1/U2/U4/U5/U6/L1. You solder 49 PCB components and plug in ANT1 per board. The Mouser list therefore becomes 28 products / 100 pieces for two boards: 98 soldered parts plus two antennas. Do not buy U2 twice. No firmware code change is required; existing GPIO assignments, flash configuration and battery/CAN fixes remain intact.

Fresh ERC, refilled DRC and schematic parity all report zero violations. `exports/antenna-g3-audit.json` verifies the changes against the immutable `history/rev-g2-before-external-antenna.zip`, in addition to the complete 55-component native audit. G.2 is retained for history; use only current G.3 files for manufacturing.

## Cable and casing

Use [enclosure v2](../../enclosure/rev-g-v2/README.md). Its split cable exit accepts the terminated cable with the lid removed. The internal saddle takes a small nylon tie, protecting the connector from cable pull. Keep a slack loop at U2, avoid sharp bends and smooth printed edges. The case is not weatherproof. Fit the antenna with all power disconnected before enabling Wi-Fi; align the tiny plug squarely and press the connector, never the cable.

Mount the adhesive element inside the car on suitable plastic outside the box, away from metal and wiring, ideally in a position with a clear path toward the house. Install adhesive onto a clean dry surface at a warm temperature (ideally 21–38 °C). Try placement before permanently sticking it down. The 300 mm cable includes the length used inside the box; it is not 300 mm of free reach beyond the wall.

## Limits

Matching the antenna connector, frequency, impedance and gain establishes a sensible prototype choice, not guaranteed better range. The selected gain is below Espressif's stated 2.33 dBi limit outside FCC certification, but the antenna type/complete product still needs its own applicable RF assessment; this is not a certification claim. Check Wi-Fi signal and reconnection in the assembled case at the actual parking position before vehicle deployment. Supplier exposed-pad DFM, printed fit, supply/current measurements and car testing remain necessary. Battery cutoff still removes Wi-Fi power at dangerously low supply voltage.

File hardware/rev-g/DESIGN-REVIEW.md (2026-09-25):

# Rev G engineering review — 13 September 2026

The requested changes are implemented in a separate revision. [Independent audit](exports/independent-audit.json), [manufacturing audit](exports/manufacturing-audit.json), [ERC](exports/erc.json), [DRC](exports/drc-final.json) and [calculations](exports/protection-calculations.json) identify the exact native files checked. Rev F hashes remain unchanged. This review supports building a prototype, not declaring it proven for permanent vehicle installation.

The preceding G.2 layout added [Adi's routing and silkscreen corrections](ADI-G2-CHANGES.md), with 1.0 mm / 0.15 mm text and 0.15 mm printing clearance enforced. Circuit, BOM and component placement remain unchanged. G.3 now substitutes the external-antenna U2 and adds off-board ANT1; all electrical geometry is retained. See [G.3 verification](ANTENNA-G3-CHANGE.md). G.5 replaces G.4 mask tents with filled/capped thermal holes and renames the device Leafy. See [current manufacturing changes](FILLED-G5-CHANGE.md).

## Input damping and protection

C15 is Panasonic EEU-FR1J470H: FR series, 47 µF, 63 V, 6.3 mm diameter, 11.2 mm height, 2.5 mm straight-lead pitch. The H suffix selects taped packaging; the untaped EEU-FR1J470 was backordered in the live basket. R21 is Vishay CRCW25121R00FKEGHP, 1 Ω, 1.5 W, pulse-resistant 2512. It connects VPWR to C15 positive; C15 negative connects to GND. This RC branch damps the input ceramics while preserving the direct regulator supply path. The 100 V input ceramics and existing F1/D1/D3 remain.

The [TI regulator datasheet, §8.4–8.5](https://www.ti.com/lit/ds/symlink/lmr36510.pdf) motivates input damping and close bypass/feedback placement. A reproducible lumped-circuit estimate in `analyze_protection.py` sweeps assumed cable inductance 0.5–10 µH, source resistance 0.1–1 Ω, effective ceramic capacitance 0.5–2.42 µF, and bulk ESR 0.21–2 Ω. For an uncharged-capacitor 16 V hot plug, maximum predicted input peak falls from **31.45 V to 24.16 V**. Peak resistor power is 270.7 W, with at most 3.87 mJ dissipated in the modeled event. The [Vishay single-pulse curves](https://www.vishay.com/docs/20043/crcwhpe3.pdf) support choosing the larger pulse-resistant part; actual pulse shape and temperature still need checking.

This model assumes a conducting ideal input diode and no active regulator load or TVS conduction. It is a comparison, not a guaranteed vehicle envelope. It excludes fast edge parasitics, PCB inductance and component nonlinearities. It does **not** prove load-dump, reverse-transient, jump-start, ISO 7637/ISO 16750 or EMC compliance. D3 is still a 24 V stand-off SMBJ TVS; its specified clamp does not by itself prove the complete chain survives every vehicle pulse. No common-mode choke was added; the user's earlier decision to defer that remains respected.

## Battery protection and uninterrupted normal operation

U5 is specifically **TPS3760A012DYYR**, the adjustable 0.8 V undervoltage, active-low open-drain, non-latching variant. It must not be substituted with an overvoltage or latching variant. Its VDD is VPWR; RESET drives U1 EN. R22/R23 are 680 kΩ / 47 kΩ, 0.1%, 25 ppm/°C. R24 = 10 MΩ and R25 = 470 kΩ create additional hysteresis. C16 bypasses VDD, C17 filters SENSE, C18/C19 set sense/recovery delay. Pin functions and delay formulas were checked against the [TPS3760 datasheet](https://www.ti.com/lit/ds/symlink/tps3760.pdf).

Rev G.1 replaces the unavailable Q1 ordering code with this Catalog-grade part. It does not carry AEC-Q100 qualification or the Q1 datasheet's 70 V / 50 ms operating allowance. Its operating maximum is 65 V; 70 V is absolute maximum only. The user accepted these prototype trade-offs. See [the change and full geometry comparison](U5-G1-CHANGE.md).

Nominal protected-supply thresholds are 11.6686 V off and 12.6774 V restart. A conservative corner calculation including resistor temperature drift, reference error, input/output leakage and a conservative interpretation of hysteresis accuracy gives **11.41–11.92 V off** and **12.22–13.13 V restart**. These are circuit estimates, not individually calibrated thresholds. Actual battery voltage is higher by D1's current- and temperature-dependent forward drop. The supervisor senses after D1; the ADC cannot infer the changing diode drop exactly.

C18/C19 are 10 µF, within TI's recommended maximum. Nominal delays are 1.27 s / 12.7 s. Assuming 4–11 µF effective capacitance and TI timing limits gives roughly 0.41–1.86 s / 4.11–17.49 s. The capacitance envelope is an assumption pending bias/temperature measurement. Repeated disturbances can shorten delay if a timing capacitor has not fully discharged. Verify first-start, slow ramps, rapid dips and restart on the bench.

A board starting from the off state may need the Leaf in READY/charging, or a **13.5–14 V current-limited bench supply**, before it boots. Do not bypass U5 to make a weak battery keep the radio online. No intentional sleep schedule disconnects normal Wi-Fi operation, but low battery must be an exception. Battery chemistry remains unconfirmed: purchase at Biltema in January does not identify the model. This design assumes a conventional lead-acid accessory battery until its label is checked.

Shutdown leakage is not zero. The capacitor's full-rated-voltage leakage limit alone is about 29.6 µA. The supervisor, divider, pull-up, regulator and TVS add more; some relevant specifications are typical rather than guaranteed maxima. A sub-0.1 mA shutdown target and low-milliamp connected target are **measurement goals**, not established performance. Measure the complete board at the battery input, including temperature and router-loss conditions. Do not assume the Leaf will recharge its 12 V battery often enough to cover an unknown load.

## Powered-off ADC isolation

U6 is **TMUX1511PWR**. Channel 1 connects the original divider/filter node BAT_DIV to GPIO0/BAT_SENSE only when 3V3 is present. SEL1 is tied to 3V3; unused channels and their selects are grounded. C11 remains upstream of the switch; C20 bypasses U6. R26 = 100 kΩ pulls the ADC side down. The [TMUX1511 datasheet](https://www.ti.com/lit/ds/symlink/tmux1511.pdf) specifies powered-off protection and the leakage bounds used here.

At 65 V VPWR, the unpowered divider node is approximately 2.918 V, below the switch's 3.6 V protected signal limit. Using ±2 µA worst-case power-off leakage with R26 gives a 0.2 V ADC-side bound. When powered, R26 loads R8, changing the nominal ADC multiplier to 32.2766. Firmware uses ADC calibration and blocks Heat on if the reading is invalid. Meter-calibrate the divider gain; separately measure D1 drop.

## Placement, buttons and assembly

Measured pad-centre copper paths changed as follows:

| Route | Rev F | Rev G |
| --- | ---: | ---: |
| U1 VCC → C3 | 8.50 mm | 3.57 mm |
| U1 FB → R2 | 8.75 mm | 4.03 mm |
| U1 BOOT → C4 | 5.62 mm | 4.26 mm |

Local ground vias and close input bypass routing are retained. Native DRC has no added waivers. KiCad's configured ignored check classes remain visible in its report; “zero violations” does not mean every optional rule was enabled.

SW1/SW2 use PTS645SL43-2 LFS. The manufacturer's straight-through-hole drawing confirms 6.5 × 4.5 mm holes: pins 1/2 form one contact group, pins 3/4 the other. The PCB assigns those groups pad numbers 1 and 2 respectively. The [January 2026 manufacturer sheet](https://www.ckswitches.com/media/1471/pts645.pdf) lists −40 to +85 °C. Older distributor sheets/metadata list a narrower range; the downloaded older drawing is used only for geometry, not temperature qualification. The series is not automotive-certified and does not establish condensation resistance.

Factory scope is six parts: U1/U2/U4/U5/U6/L1. G.5 requires all 18 U1/U2 thermal holes epoxy-filled and copper-capped, with continuous top mask openings. JLC normal stencil engineering is accepted. Supplier fabrication/assembly review and physical solder-joint/bench checks remain; static audits cannot prove the completed manufacturing process. See `MANUFACTURING-NOTES.md`.

## Required prototype tests

1. Inspect all component orientations and joints; confirm no power-rail shorts. Hold ESP_EN low and power through J1 with current limiting. Sweep above the recovery threshold, then down through cutoff. Record VPWR and raw battery thresholds/delays at several temperatures and with rapid dips.
2. Scope U1 VIN/3V3 at startup, hot plug and Wi-Fi bursts; verify ESP32 rail remains 3.0–3.6 V, check ripple and load steps. Confirm C15 polarity and R21 pulse temperature. Laboratory transient testing is required before claiming automotive robustness.
3. Confirm ADC calibration, power-off isolation and shutdown current. Connect UART only while the board is powered; remove UART before removing board power.
4. Keep the board on the router for at least 24 hours; measure input current. Reboot/disconnect the router repeatedly, test weak signal, DHCP renewal and clients on the same LAN. Ensure no stale On request replays and no unintended CAN traffic occurs while idle.
5. Verify DB9/OBD continuity, actual TCU disconnection and likely 2013–2015 profile. Bench-test CAN with a correctly terminated second node first. Only then enable CAN writing and test Heat on/Off beside the car, including disconnected Wi-Fi and the local Off timer. Verify the car's own climate timeout: loss of board power cannot guarantee sending Off.

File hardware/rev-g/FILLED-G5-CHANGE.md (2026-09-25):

# Leafy G.5 — filled thermal holes and simpler assembly instructions

G.5 replaces the unfilled, top-tented U1/U2 thermal-hole process with epoxy fill, planarization and copper capping. The product name printed on the PCB is now **Leafy**. The preserved input is `history/rev-g4-before-filled-g5.zip`, with a per-file SHA-256 baseline manifest.

## What changes

- Remove the small solder-mask tents and their fragmented mask polygons under U1/U2. Use one continuous top mask opening: U1 2.71 × 3.40 mm and U2 2.70 × 2.70 mm.
- Require all six 0.33 mm U1 holes and twelve 0.30 mm U2 holes to be epoxy-filled and copper-capped. The unchanged drill artwork is accompanied by a coordinate CSV and location drawing. Merely selecting the global filling option is insufficient for U1's 0.33 mm holes and thermal PTH-pad classification.
- Retain the bottom mask artwork; those openings expose the finished capped annuli. They no longer mean physically open holes.
- Use Standard assembly and JLC's normal stencil engineering. Retain native paste as a reference, without requiring its exact apertures or a fixed stencil thickness. Select Special stencil = No.
- Replace the printed LEAF HEAT name with Leafy and revision G.5. Update native titles and U1/U2 footprint identifiers to identify the process.

## What remains compatible

All 55 component MPNs/values, 49 hand-fitted parts, six factory-fitted parts, antennas, pin nets, copper geometry, drills, solid thermal connections, connector positions, mounting holes and finished outline are unchanged from G.4. The hand BOM, Mouser shopping files and JLC placement coordinates/angles remain unchanged. The user has received the Mouser parts; no additional parts are required for this revision. The compatibility audit checks the saved supplier quantities, not the physical delivered bags.

No firmware change or enclosure geometry change is required. Existing enclosure renders show earlier artwork and are not relabelled as G.5 renders. Native KiCad renderers still show drilled holes because physical resin fill/capping is a fabrication operation; the fabrication notes and hole map control that process.

## Verification

`audit_filled_g5.py` checks native copper/stackup/drill/mechanical equivalence, schematic net equivalence, all component identities, saved Mouser quantities, placement files and final Gerber mask geometry against the preserved baseline. It checks actual plotted top-mask openings over all 18 thermal holes. Four copper Gerbers, drill files, bottom mask and reference paste must be unchanged after header normalization. Fresh KiCad ERC and DRC include zone refill and schematic parity.

These are artwork/compatibility checks. Actual filling/capping, normal assembly process acceptance and prototype measurements remain fabrication/bench tasks. Do not manufacture the newly exposed thermal holes without filling/capping.

## Sources and supplier correspondence

- JLC email: epoxy fill requires Horizontal Electroless Copper Plating; estimated combined surcharge USD 21.06; default holes <= 0.30 mm, special sizes must be remarked.
- Swee's assembly review: Standard assembly recommended; JLC uses its component-library stencil process. The user chose a new Standard order with normal stencil engineering.
- [JLC via covering](https://jlcpcb.com/help/article/pcb-via-covering): filling/capping and thermal-hole identification.
- [JLC SMT stencil workflow](https://jlcpcb.com/help/article/smt-stencil-data-prepared-for-smt-orders): assembler-generated stencil data.
- [TI LMR36510 datasheet](https://www.ti.com/lit/ds/symlink/lmr36510.pdf): DDA pad/mask and assembly-site stencil guidance.
- [Espressif module datasheet](https://documentation.espressif.com/esp32-c3-wroom-02_datasheet_en.pdf): EPAD paste quantity must not compromise perimeter joints.
- [JLC rails/fiducials](https://jlcpcb.com/help/article/how-to-add-edge-rails-fiducials-for-pcb-assembly-order): temporary tooling for Standard assembly.

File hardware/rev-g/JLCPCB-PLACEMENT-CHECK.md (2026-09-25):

# Leafy G.5 — placement check for the NEW order

The component positions, MPNs, lead geometry and corrected JLC CPL are unchanged from G.4. The six catalogue offsets were verified in earlier JLC previews. The new G.5 order still needs its own preview check: historical approval is not current approval.

| Part | JLCPCB code | Native KiCad angle | JLC angle | Required physical alignment |
| --- | --- | ---: | ---: | --- |
| L1 | C2044314 | 0° | 0° | Centred, both terminals aligned, nonpolar |
| U1 | C1858393 | 0° | 270° | Eight leads aligned; pin one upper-left |
| U2 | C2926676 | 0° | 0° | External-antenna 02U model; all eighteen outer castellations aligned, pin one upper-left, socket upper-right |
| U4 | C7519 | 90° | 0° | Six leads aligned; pin one lower-left |
| U5 | C5218894 | 0° | 270° | Fourteen leads aligned; pin one upper-left |
| U6 | C2866750 | 0° | 270° | Fourteen leads aligned; pin one upper-left |

`CPL-FACTORY-JLCPCB.csv` already includes the catalogue corrections. Do not rotate it again. `CPL-NATIVE-REFERENCE-ONLY.csv` and `placements-FACTORY.csv` are reference files, not the JLC upload. Use `FACTORY-PIN1-REFERENCE.csv` for independent physical pad-one coordinates (origin lower-left, X right, Y up).

U2 is the ESP32-C3-WROOM-02U-N4 with an external antenna socket. Its origin is (73,92) mm in the exported coordinate system; pin one is (64.25,98) mm. Fit the specified C2926676 and keep the cable socket accessible.

Only U1/U2/U4/U5/U6/L1 are factory assembled. The other 49 components and external ANT1 are customer fitted. Factory paste Gerbers are reference only; normal JLC stencil engineering is accepted. U1/U2 require the G.5 filled/capped process from the fabrication notes. Do not power or program the partial assembly.

Retain manual placement confirmation for the new upload. Historical cart/order records, screenshots and source documents are preserved under `quotations` and the G.4 baseline archive.

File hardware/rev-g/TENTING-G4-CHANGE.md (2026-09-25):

# G.4: component-side thermal-hole tents and controlled paste

G.4 supersedes G.3 for manufacturing. This is a **fabrication/assembly process revision**, retaining every electrical pad, trace, via, drill, connection, component MPN, placement and case interface. The factory still fits U1/U2/U4/U5/U6/L1 on two boards. Mouser quantities and all hand parts are unchanged.

The original G.3 project, outputs and quotation records are preserved in `history/rev-g3-before-tenting.zip`. Do not order the old G.3/Y9 fabrication entry as G.4. The schematic and BOM footprint identifiers now point to the two G.4 local footprints.

## Implemented geometry

Both thermal-hole groups remain unfilled plated through holes. **TOP / component-side mask covers the holes; the bottom ends remain open.** No epoxy filling, copper cap or bottom-only tenting is claimed. The drawings are positive solder-mask openings: the covered hole regions are absent from the exported top mask. A general website “Tented” choice cannot substitute for this geometry.

| Feature | U1, LMR36510ADDAR | U2, ESP32-C3-WROOM-02U-N4 |
| --- | --- | --- |
| Existing holes retained | Six, nominal 0.33 mm | Twelve, nominal 0.30 mm |
| Top mask cap | 0.65 mm square; outer rows connect to pad-edge mask | 0.62 mm diameter; circular polygons, outer caps connect to edge mask |
| Nominal radial hole-edge coverage | 0.160 mm minimum | About 0.1596 mm minimum |
| Overall thermal mask envelope | 2.71 × 3.40 mm | 2.70 × 2.70 mm within existing 2.90 mm copper |
| Top paste | Two 2.71 × 1.55 mm openings, 0.30 mm central web | Nine 0.60 × 0.60 mm openings on existing 1.10 mm pitch |
| Nominal stencil thickness requested | 0.125 mm | 0.125 mm |
| Geometric paste area / wet volume | 8.401 mm² / 1.0501 mm³ | 3.240 mm² / 0.4050 mm³ |

The U1 mask keeps 6.484 mm² exposed within the 9.214 mm² envelope (70.37%). The U2 round caps avoid the narrow diagonal mask connections that square caps would create on its staggered grid. Actual areas and hole coverage are measured from the final plotted Gerbers in `exports/tenting-g4-audit.json`, not inferred from a viewer checkbox.

U1 follows the current DDA0008B mask envelope. Its two stencil windows deliver 91.18% of the nominal paste volume of TI's single 2.71 × 3.40 mm opening at 0.125 mm thickness, allowing a central release/venting web. Some paste deliberately prints over the mask tents and should coalesce onto adjacent exposed copper during reflow. **The tents must survive processing.** These dimensions are an engineering proposal requiring assembler acceptance, not a claim that JLCPCB has approved the process.

U2's central paste drops from nine 0.70 mm squares to nine 0.60 mm squares to suit the reduced exposed area and avoid lifting the module. The eighteen perimeter pads and their paste are unchanged. Espressif permits the central EPAD to remain unsoldered; when it is soldered, paste volume must not compromise the outer joints. G.4 retains central soldering and thermal copper, but its actual thermal performance and joint quality still require inspection/testing.

Do not assume a website quote's default stencil thickness matches this design. Ask JLCPCB to confirm **0.125 mm**, or provide its proposed thickness, final apertures and resulting paste volume for review. At 0.125 mm, the thermal-aperture area ratios exceed 0.66; this does not prove transfer efficiency. No automatic blanket stencil enlargement, merged thermal apertures, or mask enlargement is authorized.

## Required supplier response before production approval

1. Confirm that the supplied **solder-mask-defined** U1/U2 geometry will be preserved, including every top-side tent. Do not convert the thermal PTHs into exposed component holes or apply a global via rule that overrides the plots.
2. Confirm mask registration, finished-hole dimensions and survival of the 0.30/0.33 mm hole tents through HASL/reflow. Nominal artwork allows over 0.076 mm radial coverage even with +0.13 mm hole diameter, considered separately; the factory must evaluate its combined drilling/registration process tolerances.
3. Confirm stencil thickness, U1/U2 aperture patterns, transfer/reflow process and exposed-pad inspection. Review U1 solder coverage/voiding and all U2 perimeter joints. If this process is unavailable, propose the required change and extra cost **before** production.
4. Return processed PCB Gerbers and final placement/stencil data for customer approval. Disable automatic PCB/placement confirmation. Do not power or program the incomplete partial assembly.

## Verification and limits

- Fresh KiCad ERC and DRC include copper refill, all track errors and schematic parity under existing rules.
- Native geometry comparison checks all copper pads, tracks, planes, holes, outline and component locations against archived G.3.
- Independently parsed manufacturing plots verify all eighteen top hole covers, open bottom ends, mask areas and stencil apertures. Four copper Gerbers and both drill files match G.3 after header normalization.
- All 55 component MPNs, the six-part assembly scope, corrected JLC rotations, hand BOM and Mouser basket quantities remain unchanged.
- The G.3 enclosure/firmware remain compatible because mechanical and electrical geometry are unchanged. Existing enclosure renders retain their G.3 provenance.

Static verification cannot establish physical mask adhesion, solder joints, heat transfer, powered circuit behavior or vehicle qualification. This revision resolves the missing mask artwork; **supplier process acceptance and physical prototype tests remain**.

## Sources checked 15 September 2026

- [TI LMR36510 Rev B, package pages 38–39](https://www.ti.com/lit/ds/symlink/lmr36510.pdf): DDA0008B mask envelope, tent/fill/plug guidance and stencil-thickness examples.
- [TI PowerPAD SLMA002H, §2.4–3.1](https://www.ti.com/lit/an/slma002h/slma002h.pdf): component-side mask caps, via size, paste/assembly and inspection guidance.
- [Espressif ESP32-C3-WROOM-02/02U, §9](https://documentation.espressif.com/esp32-c3-wroom-02_datasheet_en.pdf): optional central EPAD soldering and excess-paste lifting risk.
- [JLCPCB via covering](https://jlcpcb.com/help/article/pcb-via-covering): via finish does not automatically apply to component PTH pads.
- [JLCPCB solder-mask-defined pads](https://jlcpcb.com/help/article/how-to-order-boards-with-solder-mask-defined-pads): explicit PCB remark and production-file review to prevent mask enlargement.
- [JLCPCB stencil process](https://jlcpcb.com/help/article/opening-process-standard-of-stencil): default aperture optimization and use of remarks for custom patterns.

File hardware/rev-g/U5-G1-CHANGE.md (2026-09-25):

# Rev G.1 — U5 availability substitution

Historical change record: the statements below describe G → G.1. Current layout/manufacturing files are **G.3**, with additional routing and silk changes documented in [ADI-G2-CHANGES.md](ADI-G2-CHANGES.md). The accepted U5 part and its qualification limits remain the same. Run the G.1 equivalence audit only against its archived source; use `audit_antenna_g3.py` and `audit_rev_g.py` for the current board.

The current build uses **Texas Instruments TPS3760A012DYYR, JLCPCB C5218894**, replacing TPS3760A012DYYRQ1 / C5218886. The user approved this prototype substitution on 13 September 2026 after reviewing the qualification and transient-specification differences.

**This is a BOM revision on the unchanged Rev G PCB layout.** Native filenames remain `leaf-heat-v7`; the physical board still says Rev G. Current ordering ZIPs say `rev-g1`. Use the six-part Rev G.1 factory BOM. The superseded Rev G release, BOMs and ZIPs are preserved in `history/rev-g-before-u5-g1.zip`.

The DYY 14-pin footprint, pinout, non-latching undervoltage action, 0.8 V reference, 2% internal hysteresis, open-drain output and relevant timing/threshold specifications match. There are no changes to routing, planes, pads, component positions, the hand BOM, firmware pin map or enclosure. The 11.67 V cutoff / 12.68 V restart estimates after D1 and nominal 1.27 s / 12.7 s delays remain unchanged. Firmware cannot maintain Wi-Fi while the hardware low-battery cutoff removes power.

The replacement is **Catalog grade and is not AEC-Q100 qualified**. Its specified operating supply maximum is 65 V; 70 V is an absolute maximum, not the Q1 part's additional 70 V / 50 ms operating-transient allowance. The swap does not establish vehicle transient robustness. Sources: [TI TPS3760 datasheet](https://www.ti.com/lit/ds/symlink/tps3760.pdf), [TI TPS3760-Q1 comparison](https://www.ti.com/lit/ds/symlink/tps3760-q1.pdf).

`audit_u5_g1.py` compares the entire parsed native PCB, schematic and symbol library with the archived release, allowing only this exact identity/datasheet replacement. It also checks all 55 component records and the unchanged hand BOM and native placement file, plus the explicit JLC rotation offsets. Fresh ERC/DRC and the independent electrical audit are separate checks; their JSON reports are in `exports/`.

The manufacturer fits U1/U2/U4/U5/U6/L1. Mouser still supplies 27 SKUs / 98 pieces for two boards; U5 must not be added to that hand-parts cart. The existing Rev G enclosure remains applicable through the full geometry-equivalence check; its original render provenance is retained, with a separate G.1 compatibility record.

## JLCPCB placement review

The revised BOM matched all six exact parts, including U5 C5218894. The user approved the catalogue rotation corrections, which were visually checked against the pads and pin-one markings and saved in the JLCPCB draft on 13 September 2026. Final JLC angles are U1/U5/U6 270°, U4 0°, and U2/L1 0°. All centres and PCB geometry remain unchanged.

`exports/CPL-FACTORY-JLCPCB.csv` now contains those JLC-specific angles, and the exporter preserves them. `exports/CPL-NATIVE-REFERENCE-ONLY.csv` and `placements-FACTORY.csv` retain native KiCad angles for independent reference and other suppliers. Do not apply the JLC offset a second time. `exports/FACTORY-PIN1-REFERENCE.csv` gives independent pad-one coordinates. See [the placement check](JLCPCB-PLACEMENT-CHECK.md) and `quotations/2026-09-13/rev-g1-status.json` for order preparation status. Final manufacturer placement approval remains required. [JLCPCB rotation convention](https://jlcpcb.com/help/article/pick-place-file-for-pcb-assembly), [catalogue orientation differences](https://jlcpcb.com/help/article/pcb-assembly-faqs-part-2).

Before manufacturing approval, obtain the assembler's decision on the U1/U2 exposed-pad thermal holes and stencil process. Before car use, perform the supply/transient/current, CAN, Wi-Fi and heater bench/vehicle tests in `DESIGN-REVIEW.md`. No powered validation or purchase is implied by the static checks.

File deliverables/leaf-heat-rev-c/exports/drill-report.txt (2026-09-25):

Drill report for leaf-heat-v3.kicad_pcb
Created on 2026-09-12T11:08:24

Copper Layer Stackup:
    =============================================================
    L1 :  F.Cu                      front
    L2 :  In1.Cu                    in1
    L3 :  In2.Cu                    in2
    L4 :  B.Cu                      back

Drill file 'leaf-heat-v3-PTH.drl' contains
    plated through holes:
    =============================================================
    T1  0.300mm  0.0118"  (122 holes))
    T2  0.300mm  0.0118"  (12 holes))
    T3  0.330mm  0.0130"  (6 holes))
    T4  1.000mm  0.0394"  (3 holes))
    T5  1.200mm  0.0472"  (9 holes))
    T6  3.200mm  0.1260"  (2 holes))

    Total plated holes count 154

Drill file 'leaf-heat-v3-NPTH.drl' contains
    unplated through holes:
    =============================================================
    T1  2.700mm  0.1063"  (3 holes))

    Total unplated holes count 3

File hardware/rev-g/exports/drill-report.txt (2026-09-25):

Drill report for leaf-heat-v7.kicad_pcb
Created on 2026-09-22T09:21:39

Copper Layer Stackup:
    =============================================================
    L1 :  F.Cu                      front
    L2 :  In1.Cu                    in1
    L3 :  In2.Cu                    in2
    L4 :  B.Cu                      back

Drill file 'leaf-heat-v7-PTH.drl' contains
    plated through holes:
    =============================================================
    T1  0.300mm  0.0118"  (169 holes))
    T2  0.300mm  0.0118"  (12 holes))
    T3  0.330mm  0.0130"  (6 holes))
    T4  0.800mm  0.0315"  (2 holes))
    T5  1.000mm  0.0394"  (3 holes))
    T6  1.100mm  0.0433"  (8 holes))
    T7  1.200mm  0.0472"  (9 holes))
    T8  1.500mm  0.0591"  (7 holes))
    T9  3.200mm  0.1260"  (2 holes))

    Total plated holes count 218

Drill file 'leaf-heat-v7-NPTH.drl' contains
    unplated through holes:
    =============================================================
    T1  2.700mm  0.1063"  (4 holes))

    Total unplated holes count 4

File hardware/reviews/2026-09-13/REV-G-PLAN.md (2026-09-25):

# Rev F verification and proposed Rev G plan

Reviewed 13 September 2026. **Plan only: no PCB, schematic, BOM, manufacturing package or enclosure was changed.**

I recommend a focused Rev G before ordering: improve the input supply and local regulator layout, add independent low-battery protection, and resolve exposed-pad assembly with the manufacturer. Keep the 100 × 100 mm board, mounting holes, Wi-Fi module, single CAN interface and hand-solder approach. The supplied audit is substantially correct; its open concerns are not evidence that the existing board is certain to fail.

## What I verified

Fresh KiCad ERC returned zero violations. Fresh DRC with copper refill, all-track reporting and schematic parity returned zero violations, unconnected items or parity issues. Re-running the existing static audit passed all **1,627 checks**. All 41 components, the four factory placements (U1/U2/U4/L1), 37 hand placements and all five manufacturing/review package hashes still agree. The PCB and schematic hashes remain identical to the released Rev F files. No additional rule exclusions were introduced.

These are CAD checks under the configured rules. They do not measure electrical operation. The first sandboxed DRC process aborted without a report; the successful rerun produced the retained report. The supporting files are [verification summary](verification-summary.json), [ERC](erc.json), [DRC](drc.json) and [existing audit rerun](independent.json).

| Supplied concern | Verification and decision |
| --- | --- |
| Input damping and transient survival | Confirmed design gap. C1 = 2.2 µF/100 V and C2 = 220 nF/100 V, both ceramic. No separate input damping branch is present. The path is J1 → F1 → D1 → VPWR, with D3 across VPWR/GND. Improve this before ordering. |
| Parked battery drain | Confirmed. U1 EN is tied to VPWR; R7/R8 measure VPWR after D1; there is no independent battery cutoff. Add hardware protection and a measured firmware power budget. |
| Regulator placement | Confirmed by summing actual routed pad-centre paths: U1.6 → C3.1 **8.500 mm**, U1.5 → R2.1 **8.747 mm**. U1.7 → C4.1 is also **5.621 mm**. Revise the small regulator cluster rather than increasing every component gap. |
| Exposed-pad assembly | Confirmed unresolved process requirement. U1 has six 0.33 mm plated thermal holes; U2 has twelve 0.30 mm holes. Existing manufacturing notes already request process review. These holes are not automatically a defective footprint. |
| Buttons | Confirmed environmental limit. The exact B3F-1000 specification is −25 to +70 °C, with no icing/condensation. Prefer a better-temperature through-hole replacement while retaining easy manual BOOT/RESET. |
| Vehicle profile and bus | Confirmed limitation. J1 pins 2/7 connect to EV-CAN; 4/5 are unconnected. Registration year alone does not establish the actual model-year/TCU arrangement. Verify the car and cable before locking the next release. |

The U3 SHDN pin is correctly grounded, and standby is pulled high during reset. Its pin functions agree with [TI's TCAN340x-Q1 datasheet](https://www.ti.com/lit/gpn/TCAN3404-Q1). The nominal regulator output is **3.3148 V**. I found no new confirmed connectivity error in these checks. The project still has no runnable heater application.

## 1. Improve input protection and damping

TI describes cable/ceramic resonance, recommends additional damped input capacitance, and asks for close local bypass and feedback placement. Its EN input also supports an external undervoltage divider. These recommendations support the proposed changes; they do not establish that Rev F will fail. See [LMR36510 §§7.3.2, 8.4–8.5](https://www.ti.com/lit/ds/symlink/lmr36510.pdf).

Add a through-hole aluminium electrolytic across protected VPWR/GND, near the regulator input. **47 µF, 63 V, 105 °C** is an initial component-selection target, not an approved part or final electrical rating. Retain C1/C2. Select the final capacitor using its ESR versus temperature, ripple rating, lifetime, physical height and the calculated clamped waveform. Provide an optional series-resistor position in the added capacitor branch so damping can be adjusted without putting resistance in the board's entire power path. The final resistor/capacitor values must follow the cable/input model and measurements.

Review F1, D1 and D3 as one protection circuit: allowable steady input, positive and negative pulses, source impedance, pulse duration, current path, diode surge limits, fuse clearing and TVS energy/temperature. A TVS wattage or the regulator's voltage rating alone cannot settle this. Define the test envelope for this Leaf's low-voltage supply rather than assuming a generic alternator load-dump requirement. [TI's input-protection reference design](https://www.ti.com/tool/TIDA-01167) illustrates why system-level conditions matter; it is not evidence that this board meets those conditions.

Deliverable before release: a short protection calculation with component margins and a bench-test specification. If the existing TVS/diode/fuse cannot meet that envelope, revise them before exporting Rev G. Do not label the board automotive-qualified based on this calculation.

## 2. Rework only the regulator cluster

Place C1/C2, C3, C4 and R1/R2 around U1 to shorten their connections and ground returns. Aim for a few millimetres of direct connection where practical, especially C3 and the FB divider; this is a design target, not a manufacturer-specified universal length limit. Keep the switch-node area compact and route feedback away from it. Retain the existing internal ground reference and intentional track widths for different current paths.

Keep 1206/1210 hand pads and enough iron access. There is no benefit in moving an essential bypass farther away merely to give it the same spacing as unrelated components. If a satisfactory local layout needs closer packing than is comfortable to solder, obtain an optional assembly price for these six local passives. The default remains hand fitting wherever the revised geometry allows it.

Deliverable: an annotated regulator close-up showing the input-current loop, VCC return, bootstrap loop and feedback path, followed by the full CAD checks. Physical startup, ripple and load-step tests remain necessary after assembly.

## 3. Add independent low-battery protection

Use a low-current voltage monitor, powered from the protected input, to hold U1 EN low on a low-battery condition. Give it deliberate hysteresis and delay so removing the load does not make it repeatedly reboot as battery voltage rebounds. It must work without the ESP32 or Wi-Fi firmware running. This disables the main regulated load; it does not eliminate every leakage path or physically isolate the complete box from the battery.

The [TPS3762-Q1 family](https://www.ti.com/lit/gpn/tps3762-q1) is one candidate for a high-voltage, low-current supervisor. Its variants differ in thresholds, hysteresis, delays and latching; no exact ordering code is selected by this plan. Choose the variant and surrounding circuit together. This small IC should be factory fitted if used, increasing the factory list from four to at least five parts. Confirm sourcing and setup cost before fixing the BOM.

A two-resistor divider on the existing EN pin is cheaper, but the datasheet's 1.157–1.300 V rising-threshold range, divider error and D1 drop make it a comparatively coarse cutoff. I would use that only if a worst-case calculation proves its entire operating window acceptable; I would not present it as a precise battery protector.

Set the actual cutoff/restart voltages after confirming the fitted 12 V battery chemistry and the car's resting/charging voltages. The voltage used for protection must represent battery voltage with a documented error budget. A dedicated protected sense divider ahead of D1 is one option; simply moving the ESP32 ADC connection to the raw input is not sufficient protection.

Review the existing R7 ADC path during shutdown: VPWR can still feed BAT_SENSE when the 3.3 V rail is off. Gate or otherwise redesign that path as needed to meet the MCU's unpowered-input limits. Check all other potential back-power paths as well. Include monitor current, divider current, regulator shutdown current, TVS leakage and temperature effects in the off-state budget.

Normal low battery should give firmware a chance to send Off before the hardware threshold is reached. **Turning off the box's power is not the same as sending Heat off to the car.** Verify the car's own climate timeout and failure behaviour; never claim that this power cutoff alone guarantees the heater stops.

## 4. Keep Wi-Fi reachable without wasting battery

Deep sleep disconnects Wi-Fi. For normal operation at home, implement modem sleep plus automatic light sleep, which Espressif documents as preserving the connection. Deep sleep can be reserved for an explicit offline condition, with bounded timed reconnect attempts. [Espressif sleep documentation](https://docs.espressif.com/projects/esp-idf/en/latest/esp32c3/api-reference/system/sleep_modes.html).

Initial engineering goals: **at most 2 mA average at the 12 V input while idle and reachable on home Wi-Fi**, and **at most 100 µA from the battery after hardware shutdown**, both to be checked over the intended temperature range. These are targets, not measured results. A continuous 2 mA load consumes 1.44 Ah in 30 days, in addition to the car's own consumption; acceptability depends on the battery and parking duration.

Measure with good Wi-Fi, weak Wi-Fi, the router off, repeated reconnects and sustained operation. Use bounded reconnect/backoff and watchdog recovery. Keep CAN in standby when idle and avoid periodic wake/poll frames that prevent the car's ECUs from sleeping. Test reset, brownout and lost Wi-Fi without replaying a stale On command. Serialize On/Off requests and validate the actual end-to-end heater behaviour, not merely successful CAN transmission.

## 5. Resolve assembly and the buttons

Ask the selected assembler to review both exposed pads, paste apertures, stencil thickness, thermal holes, reflow and inspection. Agree the process before manufacturing. Prefer an accepted standard small-via process if it meets the package requirements; obtain a separate price if filled/capped holes are required. Tenting is not equivalent to filling. TI explains solder loss and the interaction of via and stencil dimensions in its [PowerPAD layout guidance](https://www.ti.com/lit/an/sloa120/sloa120.pdf). Do not delete thermal connections merely to make fabrication cheaper.

Keep manual BOOT and RESET useful for a beginner. Review a through-hole **C&K PTS645** option as a replacement for SW1/SW2: the current [series datasheet](https://www.ckswitches.com/media/1471/pts645.pdf) gives −40 to +85 °C. Confirm the exact variant's hole pattern, internally connected pin pairs, actuator height, signal-current suitability and Mouser stock before substitution. This improves the temperature range; the series is not automotive-qualified and does not establish condensation protection. The [current Omron specification](https://components.omron.com/sites/default/files/datasheet_pdf/A070-E1.pdf) supports the original audit's limitation.

If sourcing or cost prevents the upgrade, make the switches optional service components and document operation using a removable programming jig. They are not required for normal Heat on/off operation.
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

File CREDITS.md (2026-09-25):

# Credits and provenance

## OVMS / Open Vehicles

Leafy began with the question: can the Leaf remote-climate function documented by OVMS be implemented in a simple Wi-Fi-only box?

The climate protocol in `firmware/leaf-heat/include/control.hpp` is derived from Open Vehicle Monitoring System 3, revision `85074a0ae7a983b308c6e2e081185492527ee073`:
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

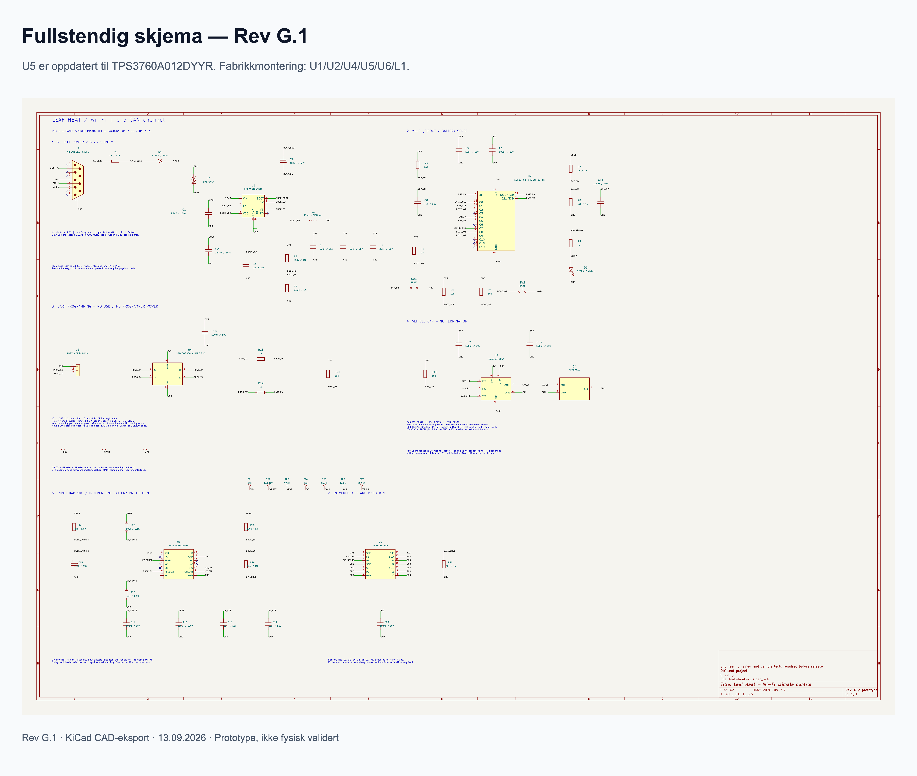
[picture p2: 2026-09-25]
hardware/rev-g/review/leaf-heat-rev-g1-bilder-til-adi/11-fullstendig-skjema.png

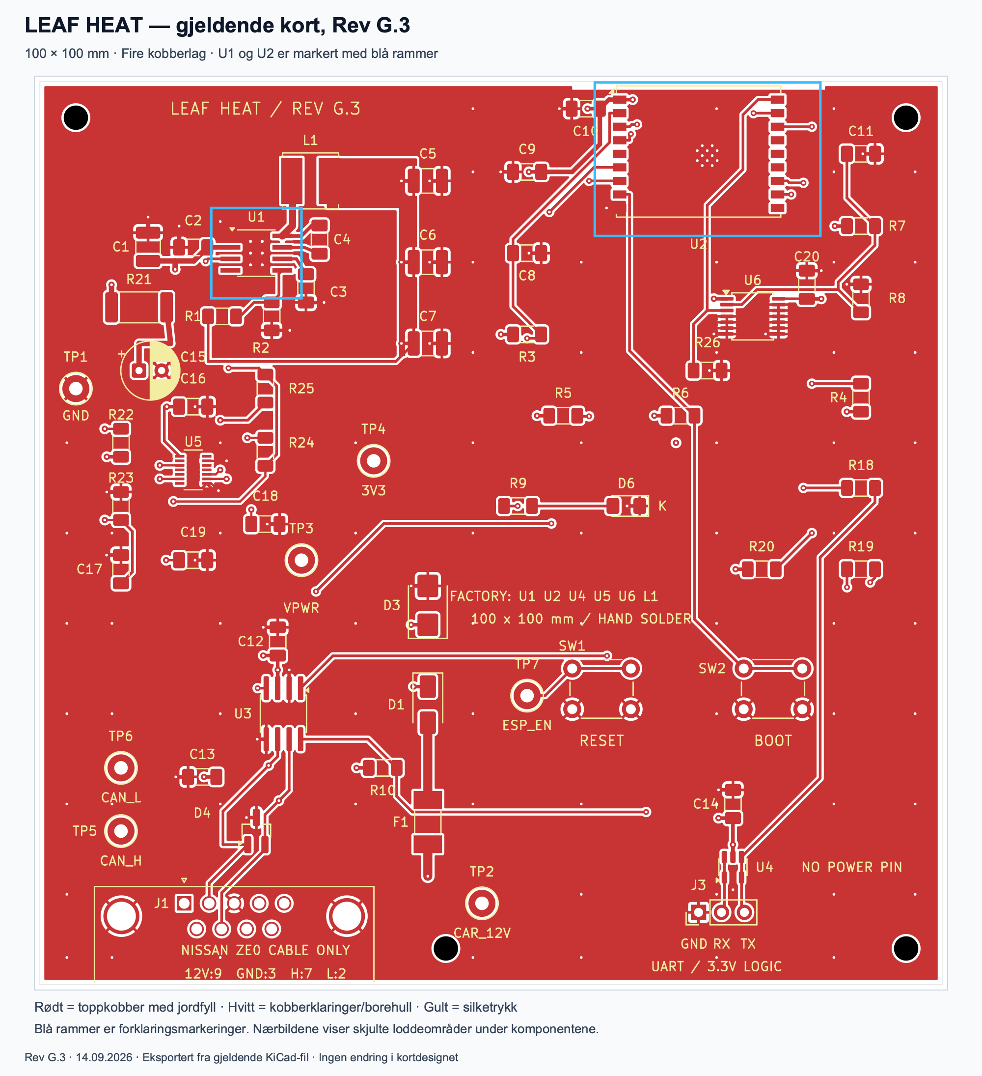
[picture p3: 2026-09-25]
hardware/rev-g/review/adi-g3-lodding-2026-09-14/01-hele-kortet-g3.png

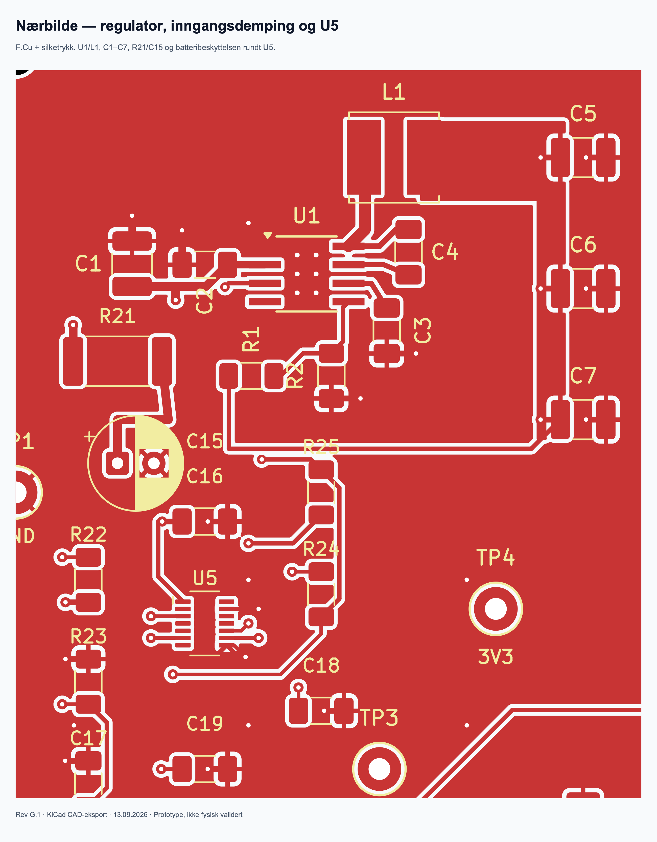
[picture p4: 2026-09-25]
hardware/rev-g/review/adi-g1-2026-09-13/06-regulator-og-u5-layout.png

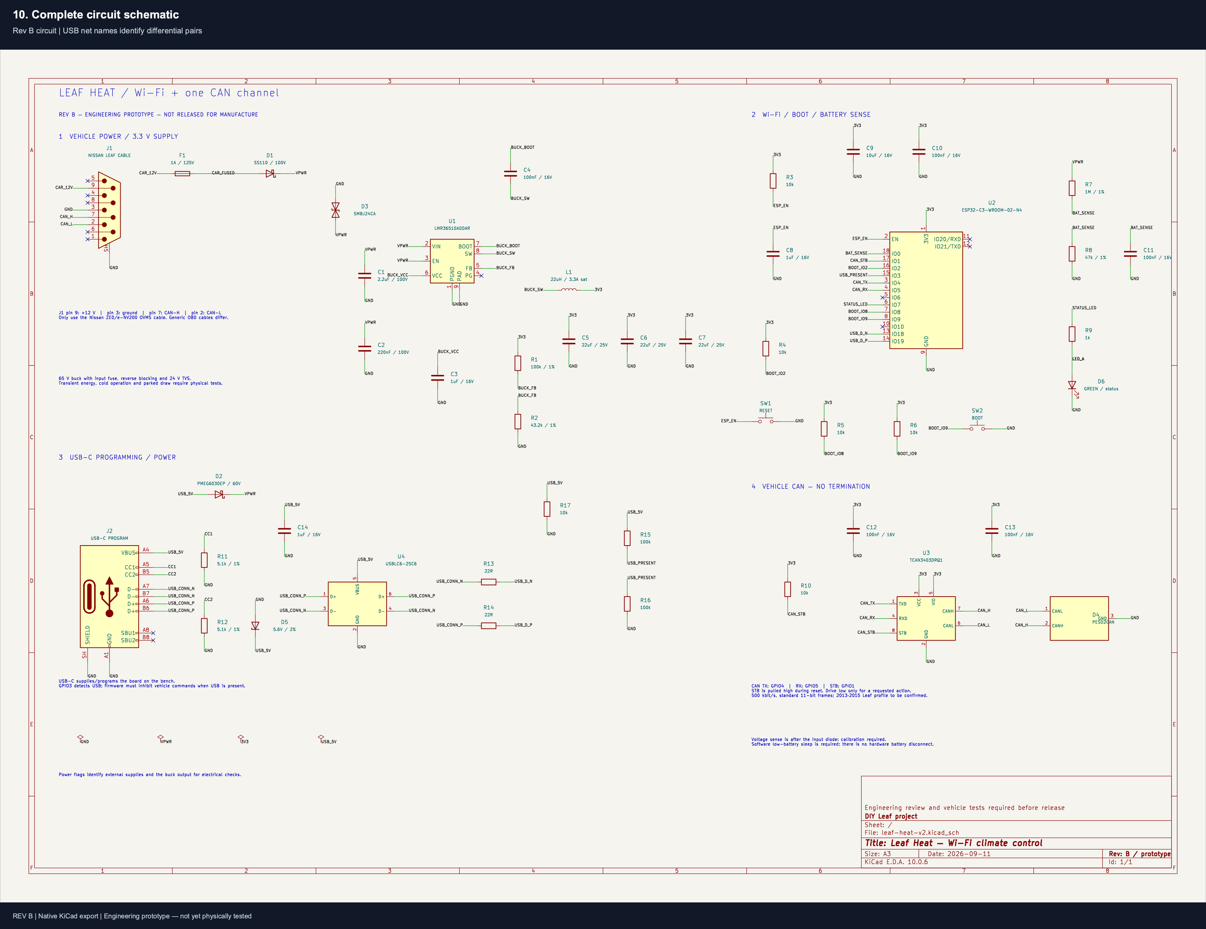
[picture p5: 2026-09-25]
deliverables/rev-b-screenshots/10-schematic.png

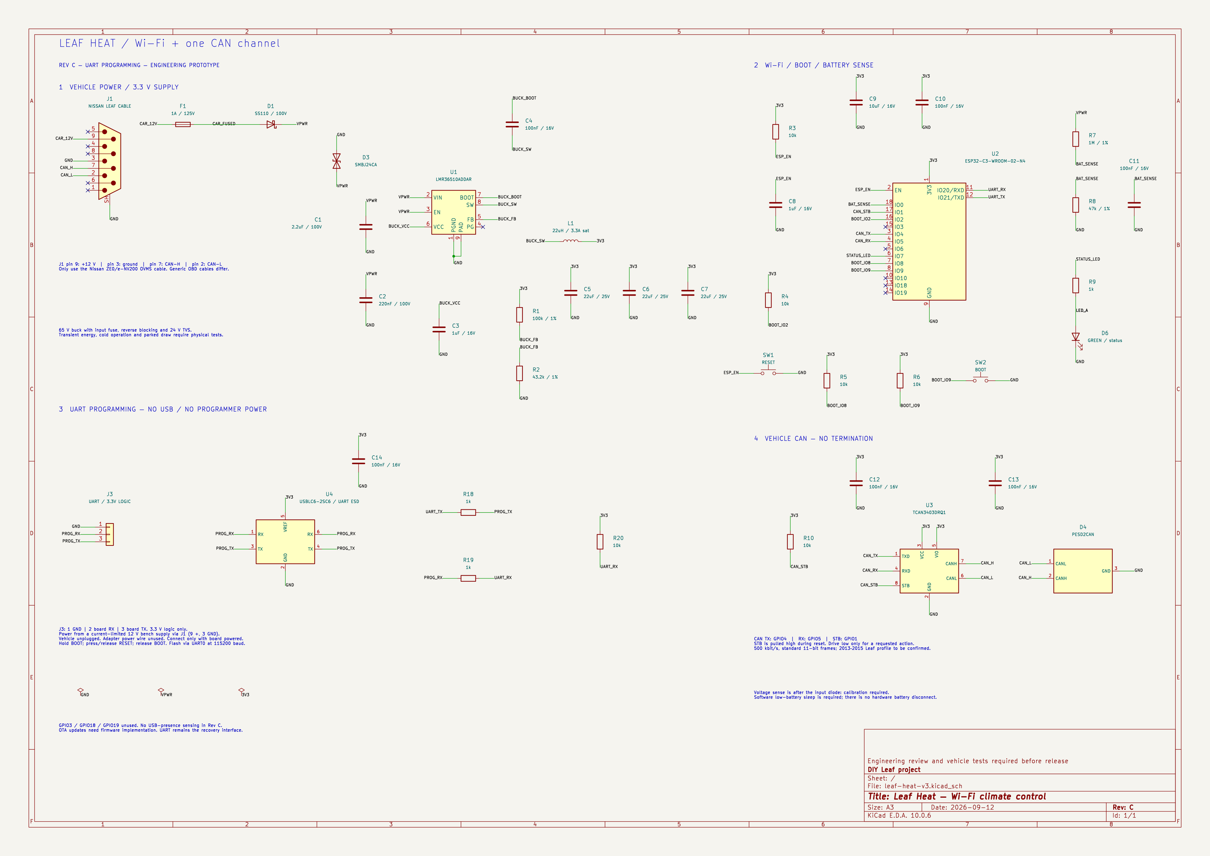
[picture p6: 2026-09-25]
deliverables/leaf-heat-rev-c/exports/schematic.png

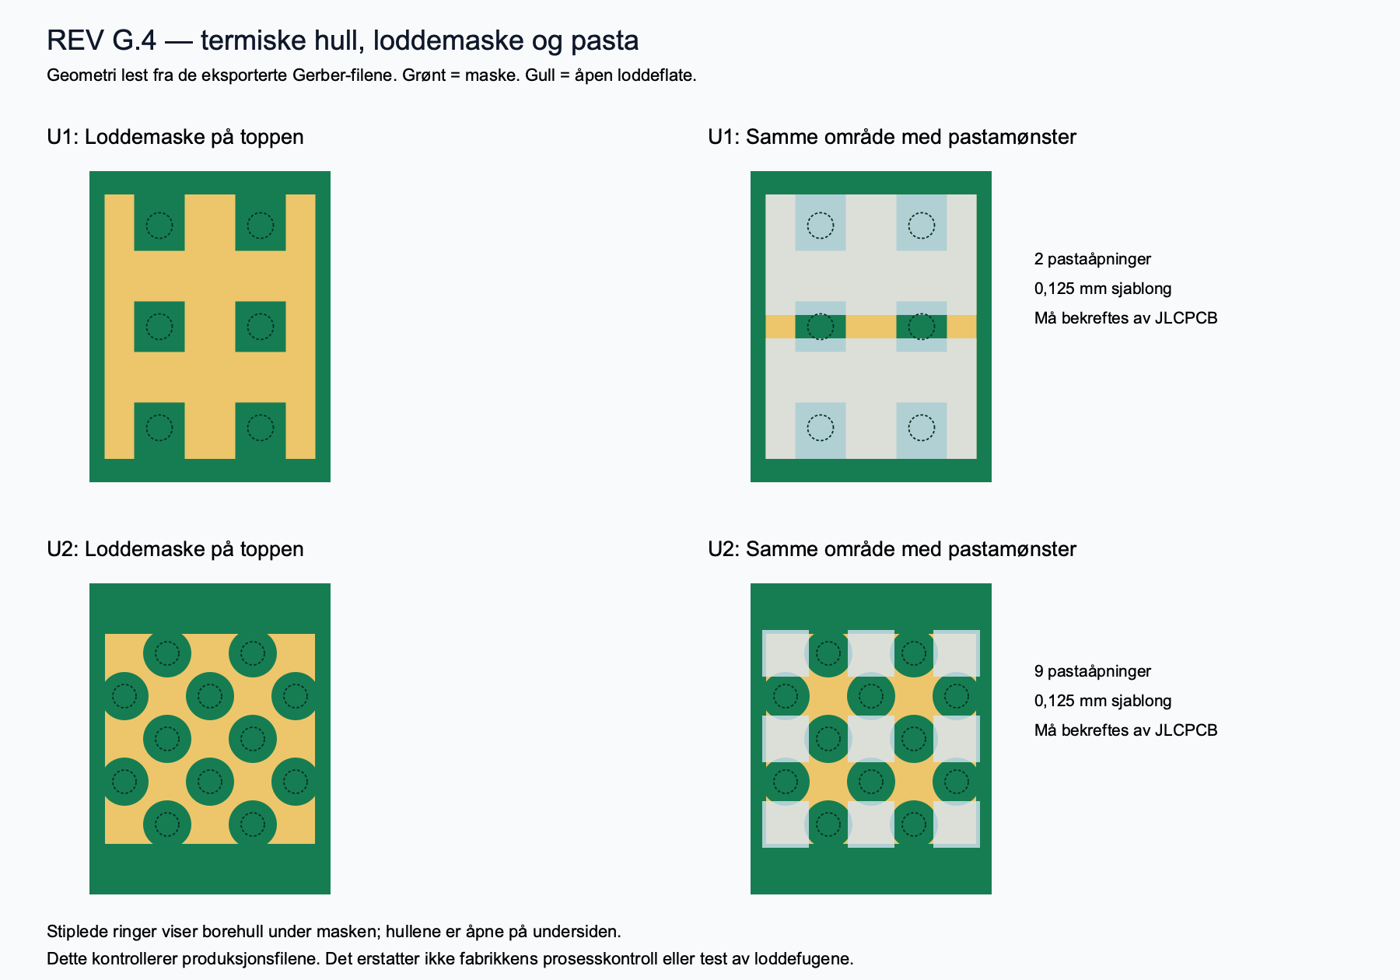
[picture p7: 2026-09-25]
hardware/rev-g/exports/tenting-g4-detail.png

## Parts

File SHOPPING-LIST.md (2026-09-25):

> **Historical development record.** The current release is [Leafy G.5](README.md). Use this file for context, not current ordering or wiring instructions.

# Shopping list: homemade Leaf Wi-Fi heater control

**Selected build: 2015 Leaf, home Wi-Fi, Heat on / Heat off only.** This replaces the earlier OVMS-kit and 4G shopping list. One programmable development board plus a passive vehicle cable forms our own controller; no OVMS module is being purchased.

| Qty | Buy | Price checked 11 September 2026 |
| --- | --- | --- |
| 1 | [Waveshare ESP32-S3-RS485-CAN](https://www.waveshare.com/product/iot-communication/short-range-wireless/esp32-s3-rs485-can.htm), onboard-antenna version | $18.99-19.99 manufacturer listing across antenna options; allow $20. Includes enclosure, Wi-Fi, CAN and power conversion. Checkout stock not verified. |
| 1 | [Nissan ZE0/e-NV200 OBD-to-DB9 cable](https://shop.openenergymonitor.com/nissan-ze0-e-nv200-obd2-ovms-cable/) | £9.94 ex-VAT; listed in stock. Choose the Nissan-specific cable. |
| 1 | [DB9 male screw-terminal breakout, Adafruit 3123](https://www.adafruit.com/product/3123) or equivalent locally | $2.95; listed in stock. Includes connector housing. |
| 1 | Inline fuse holder with 1A fuse | Allow $3-6 equivalent locally; confirm against startup draw/wire rating. |
| 1 set | Short stranded wires, heat-shrink, mounting ties/pads | Allow $3-7 equivalent locally. Keep the CAN pair twisted. |
| 0-1 | USB-C data cable | Reuse one, or allow $3-6. |

**Published core subtotal: $21.94-22.94 + £9.94.** With accessories: **$30.94-41.94 + £9.94**, excluding freight, taxes, tools and labor. Allow approximately $45-60 equivalent for the hardware; this is not a delivered-price quote. Consolidate the small parts locally where possible to avoid separate shipping charges.

No separate ESP32, CAN transceiver, MCP2515 board, power converter or main enclosure is needed with this board. Its unused RS485 interface stays unused.

## Wiring reference

For the specific Nissan cable above, connect its DB9 breakout terminals as follows:

| DB9 terminal | Destination |
| --- | --- |
| 9 | Board power positive through fuse |
| 3 | Board power negative |
| 7 | Board CAN H |
| 2 | Board CAN L |

These correspond to OBD pins 16, 4, 13 and 12 respectively, per the cable supplier's mapping. Continuity-test with the cable unplugged. Leave CAN termination disconnected. **Unplug the car cable before USB programming:** [Waveshare warns against powering from USB and the terminal block together](https://www.waveshare.com/wiki/ESP32-S3-RS485-CAN).

The initial 2013-2015 climate profile needs the original TCU unplugged if fitted. Check the actual TCU/build generation before enabling commands; registration year alone does not resolve late-year model changes. A later TCU would change the CAN pair and protocol, not the board order.

See the [current build and firmware plan](LEAF-HEAT-WIFI-PLAN.md) for the sequence, local web controls and parked-power tests. Hardware and firmware are not yet tested on the car.

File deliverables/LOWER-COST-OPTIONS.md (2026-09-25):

# Lower-cost Leaf heater box options

**Superseded by live quotations later on 12 September 2026:** the user requires a custom assembled PCB and has rejected the module route below. The manufacturer minimum batch has now been approved for quotations only. PCBWay files are submitted for review; JLCPCB's actual current-BOM quote has substantial part-loading fees and missing parts. Use the current custom-board comparison (private supplier record omitted), not the preliminary recommendation below.

Researched 12 September 2026. Scope: one or two assembled units, home Wi-Fi, heater on/off. Prices are USD unless marked otherwise. No orders or new requests for quotation were submitted during this research; the PCB design and its manufacturing requirements are unchanged.

## Recommendation

For our **own custom PCB**, JLCPCB Economic assembly is the strongest next candidate to quote for two assembled boards. Its lower setup charge is promising, but a complete component match and checkout quote are needed before calling it cheaper.

For the **lowest hardware cost and least soldering**, return to the original module-based approach: an assembled Waveshare ESP32-S3-RS485-CAN plus the correct Leaf cable and simple wiring. This avoids commissioning a PCB. It remains a development project requiring firmware and vehicle testing, not a ready-to-use Leaf accessory.

## Comparison

| Route | Finished quantity | Price evidence | What remains outside that price |
|---|---:|---|---|
| PCBWay, existing requirements | 1 assembled + 4 blank spares | Previous calculator estimate **$111.75** | Components, VAT/import costs, box and cable |
| PCBWay, without paid impedance-control service | 1 assembled + 4 blank spares | New calculator estimate **$60.16**, with slower Norway shipping and promotion | Same exclusions; also requires an intentional USB manufacturing decision |
| JLCPCB Economic | Minimum 2 assembled | **$8.18 setup**, plus other charges; complete total unknown | PCB fabrication, parts, stencil, component loading, assembly operations, shipping/tax |
| Elecrow | Advertises minimum 1 assembled | Project-specific quotation required | All project costs need pricing |
| Seeed Fusion | Minimum 1 assembled from minimum 5 blanks | Project-specific quotation required | All project costs need pricing |
| Waveshare assembled module | 1 | **$18.99–$19.99** for the module | Leaf cable, wiring/fuse, shipping/tax, firmware and testing |

Manufacturer minimum fabrication batches and the number assembled are different. Only one or two *finished* boards does not necessarily mean only one or two blanks are fabricated. PCBWay's five-board batch has not been approved or submitted.

## What drives PCBWay's price

I compared the same 65 × 50 mm, four-layer, 1.6 mm board in a separate anonymous calculator session. Both configurations used standard lead-free HASL, green mask, white silkscreen, 1 oz outer/inner copper, and normal manufacturing time. Switching off impedance control changed fabrication from **$81.36 to $31.16**, a **$50.20** difference.

The lower comparison then showed:

| Item | Amount |
|---|---:|
| Five blank PCBs | $31.16 |
| Assembly labour for one, promotional | $29.00 |
| PostNL shipping to Norway | $18.83 |
| Discount | −$18.83 |
| **Calculator total, excluding components** | **$60.16** |

The displayed shipping time was 11–33 business days. Promotions and shipping eligibility can change when the components are added. This is an online estimate, not a reviewed factory quotation. The $51.59 difference from the previous total includes both the fabrication reduction and a small net shipping reduction. [PCBWay calculator](https://www.pcbway.com/orderonline.aspx)

This is **not permission to manufacture the existing files without their requirements**. Rev B specifies a 90 Ω ±10% USB differential pair. Removing the service removes assurance of that controlled result. We would need to review the actual standard stackup and USB geometry, revise the procurement requirements deliberately, and test the resulting hardware. Alternatively, a future revision could remove USB and use an external serial programmer.

## JLCPCB: the best next custom-board quote

JLCPCB advertises two-board minimum prototype assembly and supports four-layer boards, small surface-mount parts and mixed assembly. Our general size and package classes appear compatible, subject to its actual design and component review. [Prototype assembly capabilities](https://jlcpcb.com/solutions/pcb-prototype-assembly)

Its current detailed fee table lists Economic setup at **$8.18**, stencil at **$1.53**, and loading at **$3.07 per distinct extended component**. There are additional placement, possible inspection and manual-soldering charges. Ten charged extended part types, for example, would add $30.70 before buying any parts; this is an illustration, not a count for our board. [Assembly pricing](https://jlcpcb.com/help/article/pcb-assembly-price)

Our BOM has 47 components across 29 manufacturer part numbers. Matching ordinary resistors and capacitors to suitable Basic or Preferred Extended catalog parts could avoid loading fees. Ratings, footprint, tolerance, temperature range and capacitor performance must still match. [Component categories and assembly FAQ](https://jlcpcb.com/help/article/pcb-assembly-faqs)

Three critical exact parts are listed for Economic and Standard assembly:

| Existing part | JLCPCB catalog entry |
|---|---|
| ESP32-C3-WROOM-02-N4 Wi-Fi module | [C2934560](https://jlcpcb.com/partdetail/ESP32-C3-WROOM-02-N4/C2934560) |
| LMR36510ADDAR power regulator | [C1858393](https://jlcpcb.com/partdetail/TexasInstruments-LMR36510ADDAR/C1858393) |
| TCAN3403DRQ1 CAN transceiver | [C31086109](https://jlcpcb.com/partdetail/TexasInstruments-TCAN3403DRQ1/C31086109) |

All three are listed as Extended. Catalog presence does not reserve stock or establish the final procurement price. The remaining BOM, especially the exact DB9 connector, still needs matching.

JLCPCB's published free impedance testing is **±20%**; precision testing is chargeable. That does **not** satisfy Rev B's **±10%** requirement by itself. A different manufacturer's stackup also requires a USB geometry review. [Standard laminated structures](https://jlcpcb.com/help/article/multi-layer-pcb-standard-laminated-structures)

## Other manufacturers

**Elecrow** advertises a one-piece PCBA minimum, turnkey sourcing and mixed surface-mount/through-hole assembly. Its full quotation includes PCB, stencil, parts and assembly, with flashing/testing if requested. It normally responds to an RFQ within about a working day. Its unconfigured $1 service listing is not a price for our assembled board. [Elecrow service](https://www.elecrow.com/maker/assembly/index), [capabilities and quotation details](https://static-cdn.elecrow.com/pcb-assembly.html)

**Seeed Fusion** permits one assembled board from a minimum five-board fabrication batch. Its FAQ advertises free PCBA shipping, but eligibility and our final component procurement costs must be verified in a real quote. It is a backup candidate, not a demonstrated saving yet. [Seeed ordering FAQ](https://support.seeed.cc/portal/en/kb/articles/seeed-fusion-pcb-assembly-service-quick-questions)

## Buying an assembled module instead

The Waveshare ESP32-S3-RS485-CAN is advertised at **$18.99–$19.99**, depending on antenna selection. It combines Wi-Fi, isolated CAN, a 7–36 V input supply, screw terminals and a case. The extra RS485 function can remain unused. [Manufacturer product page](https://www.waveshare.com/product/iot-communication/short-range-wireless/esp32-s3-rs485-can.htm)

Example additional hardware:

| Item | Price evidence |
|---|---|
| Correct Nissan ZE0 / e-NV200 OVMS cable | [£9.94 excluding VAT](https://shop.openenergymonitor.com/nissan-ze0-e-nv200-obd2-ovms-cable/) |
| Assembled male DB9 screw-terminal adapter | [$2.95](https://www.adafruit.com/product/3123) |
| Inline fuse, holder and short wires | $6–$13 planning allowance, not a supplier quote |

Allow roughly **$45–$60 for prototype hardware before shipping/tax**, including some allowance for small accessories. This is a budget estimate across currencies and suppliers, not a checkout total; separate shipping charges could be significant. Reuse a USB cable if available. The screw-terminal approach avoids fine-pitch soldering.

The advertised input-voltage range does not establish automotive transient qualification. Firmware, parked battery consumption and power robustness still need verification before permanent installation. Use the Leaf-specific EV-CAN wiring and do not add a CAN termination resistor to the car's existing bus. Both our custom board and this module route still require working heater-control software and vehicle tests.

## Changes worth considering only if we keep a custom PCB

1. First quote two units at JLCPCB with our existing circuit and suitable catalog parts. Avoid redesigning before knowing the real savings.
2. Keep the four-layer ground-plane layout and the power/CAN protection. They are not the first places to cut cost.
3. If USB remains a significant fabrication or assembly cost, consider a revision with a simple programming header instead. This requires a proper reset/boot and power arrangement.
4. If sourcing or assembling the DB9 is disproportionately expensive, price factory assembly of all small parts with only that large connector soldered locally. Compare the actual saving before choosing this compromise.

The immediate decision is therefore whether owning a custom PCB matters more than minimizing the price of the first working prototype. For custom fabrication, obtain a complete JLCPCB two-unit quote. For the cheapest prototype, develop and test around the assembled module.

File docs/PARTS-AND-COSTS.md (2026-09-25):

# Parts and prototype costs

Use exact MPNs and packages. Saved quantities can reconstruct a basket; stock and prices must be rechecked.

## Factory components

| Ref | Part | JLC code |
| --- | --- | --- |
| U1 | LMR36510ADDAR | C1858393 |
| U2 | ESP32-C3-WROOM-02U-N4 | C2926676 |
| U4 | USBLC6-2SC6 | C7519 |
| U5 | TPS3760A012DYYR | C5218894 |
| U6 | TMUX1511PWR | C2866750 |
| L1 | SRN6045TA-220M | C2044314 |

One of each is installed on each of two assembled boards. Larger procurement quantities may reflect minimum buys/attrition, not extra placements. These parts are not duplicated in the required Mouser hand-parts list.

## Hand-parts and equipment

- [Required two-board CSV](../hardware/rev-g/exports/MOUSER-TWO-BOARDS.csv): 27 hand-part product types plus antenna; 98 soldered parts and two antennas, **100 pieces total**.
- [Complete basket with supplies](../hardware/rev-g/exports/MOUSER-CART-WITH-SUPPLIES.csv): alternative complete import including spares/tools, not an additional list to add on top.
- [Extras breakdown](../hardware/rev-g/exports/MOUSER-CART-EXTRAS.csv).

The antenna is **Molex 1461530300**, flex type with 300 mm lead and matching MHF I / U.FL-class connector. Mount it outside the box on suitable plastic inside the car, away from metal. The entire lead includes the length routed within the case.

Also needed: correct Nissan OVMS cable, soldering iron, meter, current-limited bench supply, print material, four nylon M2.5 × 8 mm screws/nuts for the PCB, four M3 × 10 mm screws/nuts for the case, and a small nylon cable tie per case. The supplies basket includes 3.3 V UART cable, flux, tweezers, braid, solder wire, jumper wires and grabber leads.

## Historical costs

The G.5 order viewed on **25 September 2026** showed:

| Item | USD |
| --- | ---: |
| Five PCBs, specified filled/capped process | 76.50 |
| Two partial Standard assemblies, after displayed coupon | 53.95 |
| Rail removal | 2.32 |
| Merchandise | **132.77** |
| Shipping | 17.17 |
| Displayed duties/taxes | 37.03 |
| Total | **186.97** |

This buys **two partially assembled boards and three bare boards**, not complete devices. The earlier $185.45 view omitted the later rail-removal charge and its tax effect. The earlier $21.06 filling/plating estimate was a process surcharge, not a total quote.

The complete Mouser basket on **14 September 2026** showed 35 product lines, **NOK 1,318.08 merchandise**, with free shipping displayed. It included spares/workshop supplies; checkout tax was not verified in that record. A later saved basket check on 16 September showed NOK 1,305.08 for the same 35 product lines and free delivery, again without verified checkout tax. The owner later reported receiving the parts. This is neither today's price nor a verified final invoice.

Cable, print material, fasteners, bench equipment and currency conversion are not included in a combined kit price. Private receipts/account identifiers are omitted. Main savings came from Wi-Fi, UART, partial assembly and reducing the 150 × 150 mm trial board to 100 × 100 mm; the final exposed-pad process adds manufacturing cost.

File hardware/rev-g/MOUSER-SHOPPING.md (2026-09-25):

# Rev G.3 Mouser basket — verified 14 September 2026

G.5 compatibility: all component MPNs and quantities remain unchanged. The user has received the Mouser parts. Leafy branding and the new filled/capped PCB process require no Mouser changes. Existing basket backup and prices remain historical observations.

**The owner's Mouser Norway Chrome basket is complete: 35 product lines covering two Rev G.3 boards, 50 spare components and seven workshop products. Every requested quantity showed “Dispatches Now”; no duplicate products or backordered items remain. Nothing was ordered.**

| Cost | NOK |
| --- | ---: |
| Hand-fitted parts, antennas and 50 spares | 671.59 |
| Seven workshop products | 646.49 |
| Merchandise total | **1,318.08** |
| Selected UPS Worldwide Express Saver delivery | **0.00** |
| Displayed basket subtotal | **1,318.08** |

Checkout taxes were not calculated or verified. The delivery amount is the current basket estimate; the final checkout has not been completed. These prices exclude the PCBs and factory assembly. The baseline remains 49 hand-fitted parts and one plug-in antenna per board; the assembler separately supplies and fits U1/U2/U4/U5/U6/L1. The vehicle cable, enclosure/fasteners, cable ties, soldering iron, meter, magnification and bench power supply are separate. A UART programmer and the small soldering supplies listed below are now included.

## Saved files

- [Complete shopping CSV with spares and supplies](exports/MOUSER-CART-WITH-SUPPLIES.csv)
- [Verified quantities, spare allocations, prices and lifecycle flags](exports/MOUSER-BASKET-WITH-SUPPLIES-VERIFIED-2026-09-14.csv)
- Mouser's original Excel export for the complete basket (private supplier record omitted)
- [Machine-readable comparison and verification record](exports/MOUSER-CART-WITH-SUPPLIES-VERIFICATION-2026-09-14.json)
- [Complete quick-order text for rebuilding an empty basket](exports/MOUSER-QUICK-ORDER-WITH-SUPPLIES.txt)
- [Required board parts and antennas only](exports/MOUSER-TWO-BOARDS.csv)
- [Added spare/supply quantities only — already included above](exports/MOUSER-CART-EXTRAS.csv)

The live Chrome basket was checked line by line. Its downloaded Excel export was independently compared with the required board quantities in `MOUSER-TWO-BOARDS.csv`, `parts.json` and `accessories.json`, plus the explicit spare/supply additions. All 35 exact Mouser SKUs, manufacturer MPNs and quantities agree. There are 157 supplier order units: 100 baseline board parts/antennas, 50 spare components and seven workshop units. A pack or reel counts as one supplier unit; this is not a count of individual wires or clips. Availability was verified separately in the live basket because the Excel export does not contain stock status. The old connector/CAN-chip customer labels now say Rev G.

The backordered untaped capacitor and the obsolete Omron buttons were removed in the earlier board-parts update. C15 remains the specified **EEU-FR1J470H** taped straight-lead version, now quantity four including two spares. The replacement C&K buttons, pulse-resistant R21, precision R22/R23 and remaining protection parts are present. No component substitution, PCB edit or manufacturing-package change was needed for the workshop/spare additions.

## Workshop supplies and spares

| Item | Mouser part number | Quantity | NOK |
| --- | --- | ---: | ---: |
| FTDI 3.3 V UART programming cable, USB-A | 895-TTL-232R-RPI | 1 | 214.05 |
| Chip Quik CQ4LF no-clean flux pen, 10 ml | 910-CQ4LF | 1 | 76.33 |
| Chip Quik fine straight ESD tweezers | 910-CQ-ESD-12 | 1 | 48.21 |
| Chemtronics 1.5 mm desoldering braid | 5878-80-2-5 | 1 | 69.19 |
| Chip Quik SAC305 lead-free solder, 0.5 mm, 1 oz (about 28 g) | 910-SMDSWLF.0201OZ | 1 | 110.15 |
| Adafruit female/female 150 mm jumper wires, pack of 20 | 485-1950 | 1 pack | 18.75 |
| Digilent mini-grabber clips with attached leads, pack of five | 424-240-137 | 1 pack | 109.81 |

The [FTDI cable](https://ftdichip.com/products/ttl-232r-rpi/) has 3.3 V logic and separate ground/TX/RX connectors. It does not power this board. Use the separately powered board and the J3 connections in the [programming instructions](../../firmware/leaf-heat/README.md). Its USB-A plug may need an adapter if the Mac has only USB-C ports; no adapter was added. The [solder datasheet](https://www.chipquik.com/datasheets/SMDSWLF.020%201OZ.pdf) specifies SAC305 alloy and a 2.2% no-clean flux core. The selected [grabber kit](https://digilent.com/shop/mini-grabber-test-clips-with-leads/) includes its leads.

The 50 spares are 46 resistors/capacitors, two F1 fuses, one U3 CAN transceiver and one D4 CAN protection device. They use exactly the already-specified component MPNs. The common 10 kΩ resistors and 100 nF capacitors have larger spare quantities. The allocation CSV records required and added quantities separately. No extra factory-supplied ICs, antenna or connector was added.

## Distributor lifecycle flags

Mouser's 14 September export marks **C1 / GRM32ER72A225KA35L as End of Life** and **D4 / PESD2CAN,215 as NRND (not recommended for new designs)**. Both required quantities were available at that check and remain the exact parts already reviewed for this prototype. These flags concern future sourcing; they do not change the ordered electrical specifications. Revisit their availability and active alternatives before a later production run. Other lifecycle fields were blank, which is not evidence of an “Active” classification.

## If the basket is lost

For an empty basket, enter all 35 part numbers and final quantities from the complete quick-order text or CSV. If a basket still exists, compare quantities before adding anything to avoid duplicates. Do not also import the extras-only list: its quantities are already included in the complete list. The original 28-product/100-piece board-only list and earlier 483.34 NOK supplier export remain preserved as history. Use cut tape/bulk quantities for the components; no full component reels or paid MouseReel service are needed. Stock and prices are a snapshot, so recheck when placing an order.

The historical JLCPCB quotation (private supplier record omitted) included the six factory parts. Use the [Leafy G.5 order guide](ORDER-G5.md) for the new Standard assembly order with filled and capped thermal holes. Its price and production-file approval must be obtained for the new order. The Mouser parts have already been received; this basket backup does not require another purchase.

Rev G.3 update: two Molex 1461530300 antennas (Mouser 538-146153-0300) added at 35.38 NOK each, 70.76 NOK total. All prior hand parts remain unchanged. U2 is factory-supplied by JLCPCB as ESP32-C3-WROOM-02U-N4/C2926676, so it is deliberately absent from this basket. The antenna needs no soldering or separate cable adapter. One small nylon cable tie per enclosure joins the existing list of mechanical supplies to obtain separately.

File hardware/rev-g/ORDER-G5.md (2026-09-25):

# Order Leafy G.5

This is the replacement design for a **new Standard PCBA order**. Do not reuse the G.4 cart/order. Check that the previous order cancellation/refund is resolved before paying for a replacement; no cancellation has been performed or verified by this file.

## Upload these three files

1. PCB: `deliverables/leafy-rev-g5-gerbers.zip`.
2. Assembly BOM: `exports/BOM-FACTORY-JLCPCB.csv`.
3. Placement: `exports/CPL-FACTORY-JLCPCB.csv`.

Attach `deliverables/leafy-rev-g5-factory-assembly.zip` as supporting engineering documentation if requested. It contains the fabrication notes and thermal-hole location drawing/CSV. Do not upload the hand BOM, full-reference BOM or native-angle CPL as the production BOM/CPL.

## Settings

| Setting | Selection |
| --- | --- |
| Finished single PCB | 100 × 100 mm, four layers |
| PCB quantity | 5 |
| Assembly type/quantity/side | Standard / 2 / Top |
| Material/thickness | FR-4 / 1.6 mm |
| Outer / inner copper | 1 oz / 1 oz |
| Mask / silk | Green / white |
| Surface finish | Lead-free HASL |
| Via covering | Epoxy Filled & Capped |
| Via plating method | Horizontal Electroless Copper Plating |
| Edge rails / fiducials | Added by JLCPCB; finished board outline unchanged |
| Depanel / remove rails before delivery | Yes |
| Special stencil | No |
| Programming / function test | No; assembly is incomplete |
| PCB production-file / parts-placement confirmation | Manual confirmation |
| Components | Exactly U1/U2/U4/U5/U6/L1 from the BOM |

Use normal JLC component handling/reflow/inspection. No custom stencil, extra paste printing, coating, functional testing or optional photo report is required. JLC's normal required charges may apply.

## PCB remark to paste

Leafy G.5: EPOXY FILL + PLANARIZE + COPPER CAP all thermal PTHs under U1 (6 x 0.33 mm) and U2 (12 x 0.30 mm), 18/PCB. Include 0.33 mm despite the default <=0.30 mm rule. See FABRICATION-NOTES.txt and THERMAL-FILL-LOCATIONS.csv. Top thermal pads have continuous mask openings; no mask tents. Bottom mask exposes copper caps, NOT open barrels. Preserve pad/copper/mask geometry and solid thermal connections. Component-lead/test/mounting holes remain open. 1 oz inner and outer copper. Manual production-file confirmation.

## Assembly remark to paste

Leafy G.5: STANDARD PCBA, fit ONLY U1/U2/U4/U5/U6/L1 TOP on 2 boards. Use supplied JLC CPL angles ONCE. Normal JLC component-library stencil engineering accepted; Special stencil=No. Paste Gerber is reference only; no fixed thickness/exact apertures, step stencil or paste on unpopulated parts. Solder U1 thermal pad; normal controlled U2 EPAD paste. Add temporary rails/fiducials and remove before delivery; preserve 100x100 mm finished outline. Manual placement confirmation. Do NOT power/program incomplete boards. ANT1 customer plug-in.

## Before payment / production

Check the new quote's total, exact six matched catalogue parts and orientations. Ensure the 0.33 mm holes are included in the filled/capped process through the explicit remark/map. Check the processed top mask has no tents and that JLC has preserved the finished outline. A normal library stencil is accepted; do not add an exact-stencil requirement again.

USD 21.06 was the estimated filling/plating surcharge for the prior discussion. It is not a complete Standard assembly quote. The old Economic price and shipping are historical. No new order or payment is created by this package. No Mouser changes are required.

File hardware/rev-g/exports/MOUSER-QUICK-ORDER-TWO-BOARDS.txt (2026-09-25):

636-182-009-113R561|2
576-0451001.MRL|2
621-B1100-F|2
576-SMBJ24CA|2
81-GRM32ER72A225KA35|2
80-C1206C224K1R|4
80-C1206C105K3R|4
80-C1206C104K5R|16
80-C1210C226K3R7210|6
603-RC1206FR-07100KL|4
603-RC1206FR-0743K2L|2
603-RC1206FR-0710KL|12
80-C1206C106K4R|6
611-PTS645SL432|4
603-RC1206FR-071ML|2
603-RC1206FR-0747KL|2
603-RC1206FR-071KL|6
859-LTST-C150KGKT|2
595-TCAN3404DRQ1|2
771-PESD2CAN-T/R|2
855-M20-9990346|2
667-EEU-FR1J470H|2
71-CRCW25121R00FKEGH|2
603-RT1206BRD07680KL|2
603-RT1206BRD0747KL|2
603-RC1206FR-0710ML|2
603-RC1206FR-07470KL|2
538-146153-0300|2

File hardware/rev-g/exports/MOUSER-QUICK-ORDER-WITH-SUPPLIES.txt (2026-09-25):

636-182-009-113R561	2
576-0451001.MRL	4
621-B1100-F	2
576-SMBJ24CA	2
81-GRM32ER72A225KA35	4
80-C1206C224K1R	6
80-C1206C105K3R	6
80-C1206C104K5R	20
80-C1210C226K3R7210	8
603-RC1206FR-07100KL	6
603-RC1206FR-0743K2L	4
603-RC1206FR-0710KL	20
80-C1206C106K4R	8
611-PTS645SL432	4
603-RC1206FR-071ML	4
603-RC1206FR-0747KL	4
603-RC1206FR-071KL	10
859-LTST-C150KGKT	2
595-TCAN3404DRQ1	3
771-PESD2CAN-T/R	3
855-M20-9990346	2
667-EEU-FR1J470H	4
71-CRCW25121R00FKEGH	4
603-RT1206BRD07680KL	4
603-RT1206BRD0747KL	4
603-RC1206FR-0710ML	4
603-RC1206FR-07470KL	4
538-146153-0300	2
895-TTL-232R-RPI	1
910-CQ4LF	1
910-CQ-ESD-12	1
5878-80-2-5	1
910-SMDSWLF.0201OZ	1
485-1950	1
424-240-137	1

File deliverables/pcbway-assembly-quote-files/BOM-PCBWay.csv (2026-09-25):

Item | Designator | Quantity | Manufacturer | Manufacturer Part Number | Description | Footprint
1 | J1 | 1 | NorComp | 182-009-113R531 | NISSAN LEAF CABLE | Leaf:NorComp_182-009-113R531
2 | F1 | 1 | Littelfuse | 0451001.MRL | 1A / 125V | Fuse:Fuse_Littelfuse-NANO2-451_453
3 | D1 | 1 | Diodes Incorporated | SS110-13-F | SS110 / 100V | Diode_SMD:D_SMA
4 | D3 | 1 | Littelfuse | SMBJ24CA | SMBJ24CA | Diode_SMD:D_SMB
5 | U1 | 1 | Texas Instruments | LMR36510ADDAR | LMR36510ADDAR | Package_SO:Texas_HTSOP-8-1EP_3.9x4.9mm_P1.27mm_EP2.95x4.9mm_Mask2.4x3.1mm_ThermalVias
6 | C1 | 1 | Murata | GRM32ER72A225KA35L | 2.2uF / 100V | Capacitor_SMD:C_1210_3225Metric
7 | C2 | 1 | Murata | GRM21BR72A224KAC4L | 220nF / 100V | Capacitor_SMD:C_0805_2012Metric
8 | C3, C8, C14 | 3 | Murata | GRM188R71C105KA12D | 1uF / 16V | Capacitor_SMD:C_0603_1608Metric
9 | C4, C10, C11, C12, C13 | 5 | Murata | GRM188R71C104KA01D | 100nF / 16V | Capacitor_SMD:C_0603_1608Metric
10 | L1 | 1 | Bourns | SRN6045TA-220M | 22uH / 3.3A sat | Inductor_SMD:L_Bourns_SRN6045TA
11 | C5, C6, C7 | 3 | Murata | GRM32ER71E226KE15L | 22uF / 25V | Capacitor_SMD:C_1210_3225Metric
12 | R1, R15, R16 | 3 | Yageo | RC0603FR-07100KL | 100k / 1% | Resistor_SMD:R_0603_1608Metric
13 | R2 | 1 | Yageo | RC0603FR-0743K2L | 43.2k / 1% | Resistor_SMD:R_0603_1608Metric
14 | U2 | 1 | Espressif | ESP32-C3-WROOM-02-N4 | ESP32-C3-WROOM-02-N4 | Leaf:ESP32-C3-WROOM-02_0p3mm_Vias
15 | R3, R4, R5, R6, R10, R17 | 6 | Yageo | RC0603FR-0710KL | 10k | Resistor_SMD:R_0603_1608Metric
16 | C9 | 1 | Murata | GRM21BR71C106KE51L | 10uF / 16V | Capacitor_SMD:C_0805_2012Metric
17 | SW1, SW2 | 2 | E-Switch | TL3342F160QG | RESET | Button_Switch_SMD:SW_SPST_TL3342
18 | R7 | 1 | Yageo | RC0603FR-071ML | 1M / 1% | Resistor_SMD:R_0603_1608Metric
19 | R8 | 1 | Yageo | RC0603FR-0747KL | 47k / 1% | Resistor_SMD:R_0603_1608Metric
20 | R9 | 1 | Yageo | RC0603FR-071KL | 1k | Resistor_SMD:R_0603_1608Metric
21 | D6 | 1 | Lite-On | LTST-C190KGKT | GREEN / status | LED_SMD:LED_0603_1608Metric
22 | U3 | 1 | Texas Instruments | TCAN3403DRQ1 | TCAN3403DRQ1 | Package_SO:SOIC-8_3.9x4.9mm_P1.27mm
23 | D4 | 1 | Nexperia | PESD2CAN,215 | PESD2CAN | Package_TO_SOT_SMD:SOT-23
24 | J2 | 1 | GCT | USB4105-GF-A | USB-C PROGRAM | Connector_USB:USB_C_Receptacle_GCT_USB4105-xx-A_16P_TopMnt_Horizontal
25 | R11, R12 | 2 | Yageo | RC0603FR-075K1L | 5.1k / 1% | Resistor_SMD:R_0603_1608Metric
26 | D2 | 1 | Nexperia | PMEG6030EP,115 | PMEG6030EP / 60V | Diode_SMD:D_SOD-128
27 | U4 | 1 | STMicroelectronics | USBLC6-2SC6 | USBLC6-2SC6 | Package_TO_SOT_SMD:SOT-23-6
28 | R13, R14 | 2 | Yageo | RC0603FR-0722RL | 22R | Resistor_SMD:R_0603_1608Metric
29 | D5 | 1 | Nexperia | BZT52-B5V6X | 5.6V / 2% | Diode_SMD:D_SOD-123

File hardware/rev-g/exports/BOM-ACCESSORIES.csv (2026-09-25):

Reference | Manufacturer | MPN | Mouser Part Number | Quantity per board | Quantity two boards | Assembly
ANT1 | Molex | 1461530300 | 538-146153-0300 | 1 | 2 | PLUG-IN / OFF-BOARD

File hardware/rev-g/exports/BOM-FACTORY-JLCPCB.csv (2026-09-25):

Comment | Designator | Footprint | Manufacturer | Manufacturer Part Number | LCSC Part #
LMR36510ADDAR | U1 | Leaf:LMR36510_DDA_FilledCapped_G5__Factory | Texas Instruments | LMR36510ADDAR | C1858393
22uH / 3.3A sat | L1 | Leaf:L_Bourns_SRN6045TA__Factory | Bourns | SRN6045TA-220M | C2044314
ESP32-C3-WROOM-02U-N4 | U2 | Leaf:ESP32-C3-WROOM-02U_FilledCapped_G5__Factory | Espressif | ESP32-C3-WROOM-02U-N4 | C2926676
USBLC6-2SC6 / UART ESD | U4 | Leaf:SOT-23-6__Factory | STMicroelectronics | USBLC6-2SC6 | C7519
TPS3760A012DYYR | U5 | Leaf:TI_DYY0014A__Factory | Texas Instruments | TPS3760A012DYYR | C5218894
TMUX1511PWR | U6 | Leaf:TSSOP-14_4.4x5mm_P0.65mm__Factory | Texas Instruments | TMUX1511PWR | C2866750

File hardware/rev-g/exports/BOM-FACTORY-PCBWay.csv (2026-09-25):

Item | Designator | Quantity | Manufacturer | Manufacturer Part Number | Description / Value | Footprint | Notes
1 | U1 | 1 | Texas Instruments | LMR36510ADDAR | LMR36510ADDAR | Leaf:LMR36510_DDA_FilledCapped_G5__Factory | FACTORY FIT. Only U1 U2 U4 U5 U6 L1 are factory-assembled; all other parts customer-fitted.
2 | L1 | 1 | Bourns | SRN6045TA-220M | 22uH / 3.3A sat | Leaf:L_Bourns_SRN6045TA__Factory | FACTORY FIT. Only U1 U2 U4 U5 U6 L1 are factory-assembled; all other parts customer-fitted.
3 | U2 | 1 | Espressif | ESP32-C3-WROOM-02U-N4 | ESP32-C3-WROOM-02U-N4 | Leaf:ESP32-C3-WROOM-02U_FilledCapped_G5__Factory | FACTORY FIT. Only U1 U2 U4 U5 U6 L1 are factory-assembled; all other parts customer-fitted.
4 | U4 | 1 | STMicroelectronics | USBLC6-2SC6 | USBLC6-2SC6 / UART ESD | Leaf:SOT-23-6__Factory | FACTORY FIT. Only U1 U2 U4 U5 U6 L1 are factory-assembled; all other parts customer-fitted.
5 | U5 | 1 | Texas Instruments | TPS3760A012DYYR | TPS3760A012DYYR | Leaf:TI_DYY0014A__Factory | FACTORY FIT. Only U1 U2 U4 U5 U6 L1 are factory-assembled; all other parts customer-fitted.
6 | U6 | 1 | Texas Instruments | TMUX1511PWR | TMUX1511PWR | Leaf:TSSOP-14_4.4x5mm_P0.65mm__Factory | FACTORY FIT. Only U1 U2 U4 U5 U6 L1 are factory-assembled; all other parts customer-fitted.

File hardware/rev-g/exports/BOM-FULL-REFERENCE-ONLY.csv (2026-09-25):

Reference | Value | Footprint | Manufacturer | MPN | Assembly | Notes
J1 | NISSAN LEAF CABLE | Leaf:NorComp_182-009-113R561__Hand | NorComp | 182-009-113R561 | HAND | Male DB9 with fork boardlocks and fitted 4-40 female screwlocks. Same 2.77 x 2.84 mm contacts and 24.99 mm anchor centres. Nissan OVMS cable pinout only; verify actual cable mating before power.
F1 | 1A / 125V | Leaf:Fuse_Littelfuse-NANO2-451_453__Hand | Littelfuse | 0451001.MRL | HAND
D1 | B1100 / 100V | Leaf:D_SMA__Hand | Diodes Incorporated | B1100-13-F | HAND | D1 ordering-code correction 2026-09-12: verified Diodes B1100-13-F, 100 V / 1 A, SMA; cathode band to pad 1 / VPWR.
D3 | SMBJ24CA | Leaf:D_SMB__Hand | Littelfuse | SMBJ24CA | HAND
U1 | LMR36510ADDAR | Leaf:LMR36510_DDA_FilledCapped_G5__Factory | Texas Instruments | LMR36510ADDAR | FACTORY | G.5: epoxy-filled/copper-capped thermal holes; JLC normal stencil process.
C1 | 2.2uF / 100V | Leaf:C_1210_3225Metric_Pad1.33x2.70mm_HandSolder__Hand | Murata | GRM32ER72A225KA35L | HAND
C2 | 220nF / 100V | Leaf:C_1206_3216Metric_Pad1.33x1.80mm_HandSolder__Hand | KEMET | C1206C224K1RACTU | HAND
C3 | 1uF / 25V | Leaf:C_1206_3216Metric_Pad1.33x1.80mm_HandSolder__Hand | KEMET | C1206C105K3RACTU | HAND
C4 | 100nF / 50V | Leaf:C_1206_3216Metric_Pad1.33x1.80mm_HandSolder__Hand | KEMET | C1206C104K5RACTU | HAND
L1 | 22uH / 3.3A sat | Leaf:L_Bourns_SRN6045TA__Factory | Bourns | SRN6045TA-220M | FACTORY
C5 | 22uF / 25V | Leaf:C_1210_3225Metric_Pad1.33x2.70mm_HandSolder__Hand | KEMET | C1210C226K3RAC7210 | HAND | 22 uF, 25 V, X7R, 10%, 1210. Fit all three output capacitors. Purchase cut tape, not a full reel. See DESIGN-REVIEW.md for DC-bias assessment and bench validation.
C6 | 22uF / 25V | Leaf:C_1210_3225Metric_Pad1.33x2.70mm_HandSolder__Hand | KEMET | C1210C226K3RAC7210 | HAND | 22 uF, 25 V, X7R, 10%, 1210. Fit all three output capacitors. Purchase cut tape, not a full reel. See DESIGN-REVIEW.md for DC-bias assessment and bench validation.
C7 | 22uF / 25V | Leaf:C_1210_3225Metric_Pad1.33x2.70mm_HandSolder__Hand | KEMET | C1210C226K3RAC7210 | HAND | 22 uF, 25 V, X7R, 10%, 1210. Fit all three output capacitors. Purchase cut tape, not a full reel. See DESIGN-REVIEW.md for DC-bias assessment and bench validation.
R1 | 100k / 1% | Leaf:R_1206_3216Metric_Pad1.30x1.75mm_HandSolder__Hand | Yageo | RC1206FR-07100KL | HAND
R2 | 43.2k / 1% | Leaf:R_1206_3216Metric_Pad1.30x1.75mm_HandSolder__Hand | Yageo | RC1206FR-0743K2L | HAND
U2 | ESP32-C3-WROOM-02U-N4 | Leaf:ESP32-C3-WROOM-02U_FilledCapped_G5__Factory | Espressif | ESP32-C3-WROOM-02U-N4 | FACTORY | G.3: U.FL external antenna connector. Fit ANT1 before enabling Wi-Fi. Pad geometry, GPIOs and 4 MB flash unchanged. G.5: epoxy-filled/copper-capped thermal holes; JLC normal stencil process.
R3 | 10k | Leaf:R_1206_3216Metric_Pad1.30x1.75mm_HandSolder__Hand | Yageo | RC1206FR-0710KL | HAND
C8 | 1uF / 25V | Leaf:C_1206_3216Metric_Pad1.33x1.80mm_HandSolder__Hand | KEMET | C1206C105K3RACTU | HAND
C9 | 10uF / 16V | Leaf:C_1206_3216Metric_Pad1.33x1.80mm_HandSolder__Hand | KEMET | C1206C106K4RACTU | HAND
C10 | 100nF / 50V | Leaf:C_1206_3216Metric_Pad1.33x1.80mm_HandSolder__Hand | KEMET | C1206C104K5RACTU | HAND
R4 | 10k | Leaf:R_1206_3216Metric_Pad1.30x1.75mm_HandSolder__Hand | Yageo | RC1206FR-0710KL | HAND
R5 | 10k | Leaf:R_1206_3216Metric_Pad1.30x1.75mm_HandSolder__Hand | Yageo | RC1206FR-0710KL | HAND
R6 | 10k | Leaf:R_1206_3216Metric_Pad1.30x1.75mm_HandSolder__Hand | Yageo | RC1206FR-0710KL | HAND
SW1 | RESET | Leaf:SW_PUSH_6mm_H4.3mm__Hand | C&K / Littelfuse | PTS645SL43-2 LFS | HAND | Straight THT, 4.3 mm actuator, 6.5 x 4.5 mm contact centres. Current manufacturer series sheet specifies -40 to +85 C; confirm supplied variant against that sheet because distributor metadata differs.
SW2 | BOOT | Leaf:SW_PUSH_6mm_H4.3mm__Hand | C&K / Littelfuse | PTS645SL43-2 LFS | HAND | Straight THT, 4.3 mm actuator, 6.5 x 4.5 mm contact centres. Current manufacturer series sheet specifies -40 to +85 C; confirm supplied variant against that sheet because distributor metadata differs.
R7 | 1M / 1% | Leaf:R_1206_3216Metric_Pad1.30x1.75mm_HandSolder__Hand | Yageo | RC1206FR-071ML | HAND | Protected VPWR divider; TMUX1511 isolates it from the unpowered MCU. ADC multiplier includes R26.
R8 | 47k / 1% | Leaf:R_1206_3216Metric_Pad1.30x1.75mm_HandSolder__Hand | Yageo | RC1206FR-0747KL | HAND
C11 | 100nF / 50V | Leaf:C_1206_3216Metric_Pad1.33x1.80mm_HandSolder__Hand | KEMET | C1206C104K5RACTU | HAND
R9 | 1k | Leaf:R_1206_3216Metric_Pad1.30x1.75mm_HandSolder__Hand | Yageo | RC1206FR-071KL | HAND
D6 | GREEN / status | Leaf:LED_1206_3216Metric_Pad1.42x1.75mm_HandSolder__Hand | Lite-On | LTST-C150KGKT | HAND | 1206 green LED. Cathode is pad 1 / GND; match package cathode mark to K on board.
U3 | TCAN3404DRQ1 | Leaf:SOIC8_Hand_Access__Hand | Texas Instruments | TCAN3404DRQ1 | HAND | Rev F only: pin 5 SHDN is tied to GND; pin 8 STB remains MCU-controlled with pull-up. Not interchangeable with TCAN3403 on this PCB.
R10 | 10k | Leaf:R_1206_3216Metric_Pad1.30x1.75mm_HandSolder__Hand | Yageo | RC1206FR-0710KL | HAND
C12 | 100nF / 50V | Leaf:C_1206_3216Metric_Pad1.33x1.80mm_HandSolder__Hand | KEMET | C1206C104K5RACTU | HAND
C13 | 100nF / 50V | Leaf:C_1206_3216Metric_Pad1.33x1.80mm_HandSolder__Hand | KEMET | C1206C104K5RACTU | HAND | Additional 3V3-to-GND bypass retained. U3 pin 5 is now SHDN/GND and must not connect to this capacitor's 3V3 terminal.
D4 | PESD2CAN | Leaf:SOT-23_Handsoldering__Hand | Nexperia | PESD2CAN,215 | HAND
C14 | 100nF / 50V | Leaf:C_1206_3216Metric_Pad1.33x1.80mm_HandSolder__Hand | KEMET | C1206C104K5RACTU | HAND | Local UART ESD reference-rail bypass.
U4 | USBLC6-2SC6 / UART ESD | Leaf:SOT-23-6__Factory | STMicroelectronics | USBLC6-2SC6 | FACTORY | UART service connector ESD protection. Pins 1/6 and 3/4 are feed-through channels; pin 5 references 3.3 V. Not a USB interface.
J3 | UART / 3.3V LOGIC | Leaf:PinHeader_1x03_P2.54mm_Vertical__Hand | Harwin | M20-9990346 | HAND | Hand solder on top. Pin 1 GND; 2 board RX (adapter TX); 3 board TX (adapter RX). No supply pin. 3.3 V logic only; no RS-232. Header origin is pin 1.
R18 | 1k | Leaf:R_1206_3216Metric_Pad1.30x1.75mm_HandSolder__Hand | Yageo | RC1206FR-071KL | HAND | UART service series resistance; 115200 baud initial programming, short leads. Not a 5 V level shifter.
R19 | 1k | Leaf:R_1206_3216Metric_Pad1.30x1.75mm_HandSolder__Hand | Yageo | RC1206FR-071KL | HAND | UART service series resistance; 115200 baud initial programming, short leads. Not a 5 V level shifter.
R20 | 10k | Leaf:R_1206_3216Metric_Pad1.30x1.75mm_HandSolder__Hand | Yageo | RC1206FR-0710KL | HAND | Hold UART RX at idle high when the programming lead is absent.
C15 | 47uF / 63V | Leaf:CP_Radial_D6.3mm_P2.50mm__Hand | Panasonic | EEU-FR1J470H | HAND | 47 uF, 63 V FR series; taped straight leads, 6.3 mm diameter x 11.2 mm height, 2.5 mm pitch. Packaging substitute for backordered EEU-FR1J470; trim leads after soldering.
R21 | 1R / 1.5W | Leaf:R_2512_Hand | Vishay | CRCW25121R00FKEGHP | HAND | Pulse-capable 2512 damping resistor; not in series with the main supply.
U5 | TPS3760A012DYYR | Leaf:TI_DYY0014A__Factory | Texas Instruments | TPS3760A012DYYR | FACTORY | Exact A012 UV, 0.8 V, 2% hysteresis, active-low open drain, NON-latching variant. Factory fit. Rev G.1: Catalog grade, not AEC-Q100; 65 V operating maximum, no Q1 70 V/50 ms operating allowance. User-approved prototype substitution.
R22 | 680k / 0.1% | Leaf:R_1206_3216Metric_Pad1.30x1.75mm_HandSolder__Hand | Yageo | RT1206BRD07680KL | HAND | Precision 0.1%, 25 ppm/C cutoff divider. Do not substitute the 1% general-purpose part.
R23 | 47k / 0.1% | Leaf:R_1206_3216Metric_Pad1.30x1.75mm_HandSolder__Hand | Yageo | RT1206BRD0747KL | HAND | Precision 0.1%, 25 ppm/C cutoff divider. R8 remains a separate 1% ADC resistor.
R24 | 10M / 1% | Leaf:R_1206_3216Metric_Pad1.30x1.75mm_HandSolder__Hand | Yageo | RC1206FR-0710ML | HAND
R25 | 470k / 1% | Leaf:R_1206_3216Metric_Pad1.30x1.75mm_HandSolder__Hand | Yageo | RC1206FR-07470KL | HAND
C16 | 220nF / 100V | Leaf:C_1206_3216Metric_Pad1.33x1.80mm_HandSolder__Hand | KEMET | C1206C224K1RACTU | HAND
C17 | 100nF / 50V | Leaf:C_1206_3216Metric_Pad1.33x1.80mm_HandSolder__Hand | KEMET | C1206C104K5RACTU | HAND
C18 | 10uF / 16V | Leaf:C_1206_3216Metric_Pad1.33x1.80mm_HandSolder__Hand | KEMET | C1206C106K4RACTU | HAND | CTS: nominal 1.27 s sense delay before DC-bias/tolerance effects. Within TI recommended maximum 10 uF.
C19 | 10uF / 16V | Leaf:C_1206_3216Metric_Pad1.33x1.80mm_HandSolder__Hand | KEMET | C1206C106K4RACTU | HAND | CTR: nominal 12.7 s recovery delay before DC-bias/tolerance effects. Within TI recommended maximum 10 uF.
U6 | TMUX1511PWR | Leaf:TSSOP-14_4.4x5mm_P0.65mm__Factory | Texas Instruments | TMUX1511PWR | FACTORY | Channel 1 isolates battery ADC. Powered-off I/O protection to 3.6 V. All unused channels grounded. Factory fit.
R26 | 100k / 1% | Leaf:R_1206_3216Metric_Pad1.30x1.75mm_HandSolder__Hand | Yageo | RC1206FR-07100KL | HAND
C20 | 100nF / 50V | Leaf:C_1206_3216Metric_Pad1.33x1.80mm_HandSolder__Hand | KEMET | C1206C104K5RACTU | HAND

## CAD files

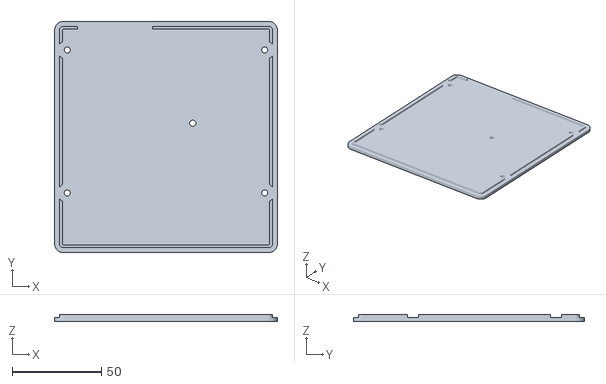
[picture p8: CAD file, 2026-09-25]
enclosure/rev-g-v1/print/leaf-rev-g-case-lid.stl
124.8 x 129.4 x 4.00

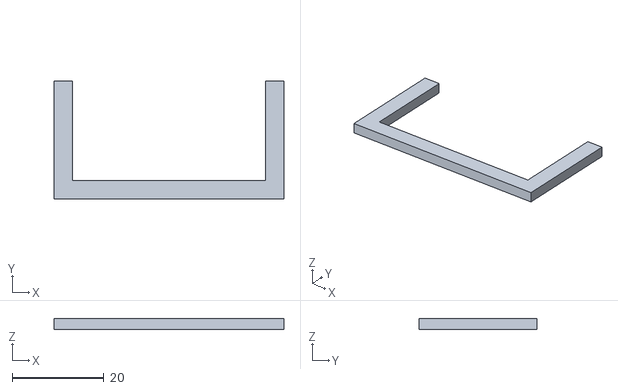
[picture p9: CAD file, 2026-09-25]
enclosure/rev-g-v2/print/OPTIONAL-connector-fit-test.stl
50.0 x 25.7 x 2.40

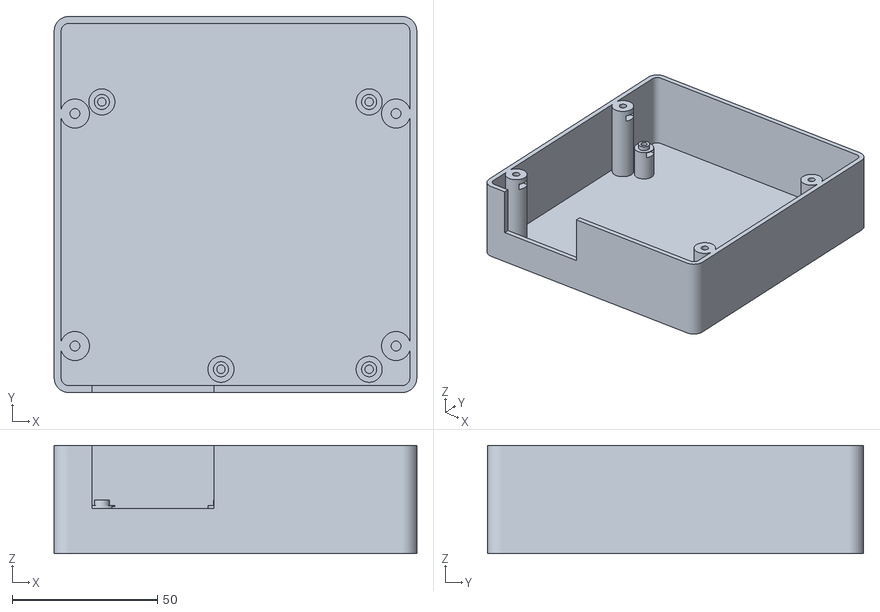
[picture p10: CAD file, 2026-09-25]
enclosure/rev-g-v1/print/leaf-rev-g-case-base.stl
124.8 x 129.4 x 37.2

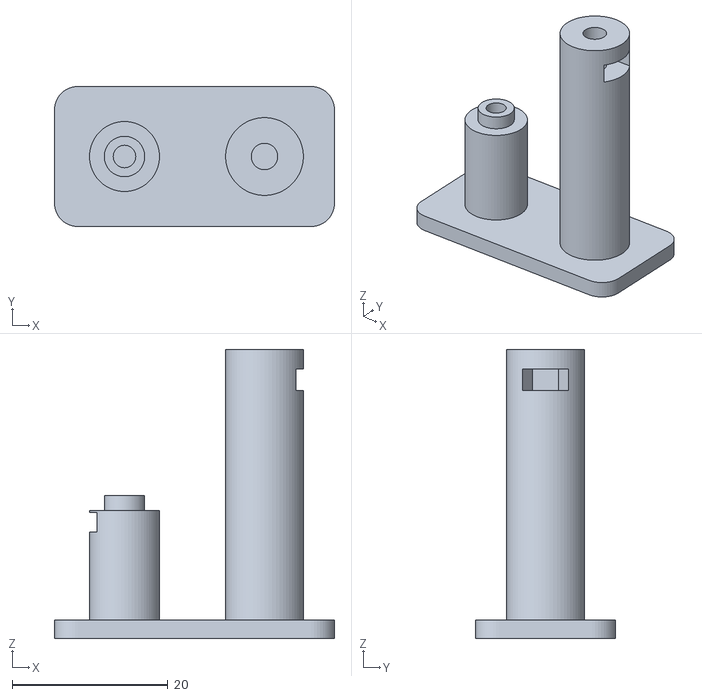
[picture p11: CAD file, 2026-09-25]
enclosure/rev-g-v2/print/OPTIONAL-fastener-fit-test.stl
36.0 x 18.0 x 37.2

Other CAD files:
enclosure/rev-g-v2/print/leaf-rev-g-case-base.stl
enclosure/rev-g-v2/print/leaf-rev-g-case-lid.stl
enclosure/rev-f-v1/leaf-rev-f-enclosure.blend
enclosure/rev-g-v1/leaf-rev-g-enclosure.blend
enclosure/rev-g-v2/leaf-rev-g-enclosure.blend

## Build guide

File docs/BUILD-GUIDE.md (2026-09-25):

# Build guide — G.5 prototype

Use a matched G.5 PCB, BOM and placement file. Read [validation status](VALIDATION.md) first.

## 1. Inspect the design

Open `hardware/rev-g/leaf-heat-v7.kicad_pro` in KiCad 10. Keep the local symbols, `Leaf.pretty/`, library tables and rules beside it. PCB Editor's 3D Viewer shows the board; a schematic PDF and assembly drawings are also included.

Native CAD and matching Gerbers are the reviewed starting point. Historical migration scripts are not a one-command release system. Read `hardware/rev-g/BUILD-REPRODUCTION.md` before regenerating anything.

## 2. Order partial assembly

Follow [ORDER-G5.md](../hardware/rev-g/ORDER-G5.md). Upload the G.5 Gerber ZIP, **BOM-FACTORY-JLCPCB.csv** and **CPL-FACTORY-JLCPCB.csv**. JLC rotations are already corrected; do not rotate them twice.

The recorded order is five four-layer PCBs, two with U1/U2/U4/U5/U6/L1 assembled on top. Confirm filling/planarization/copper caps on all eighteen thermal holes, explicitly including 0.33 mm. Use G.5 fabrication notes, not older tenting/stencil instructions. The factory must not power/program the incomplete boards. Review CAM and placement for each new order.

## 3. Hand assembly

Use [the required two-board parts list](../hardware/rev-g/exports/MOUSER-TWO-BOARDS.csv) and [HAND-ASSEMBLY.md](../hardware/rev-g/HAND-ASSEMBLY.md). A separate complete basket includes spares/tools; do not import both as cumulative quantities. Buy the correct passive cable, fasteners and bench equipment separately if needed.

Check each value, polarity and joint against the assembly image and back-side table. Practice surface-mount soldering first, particularly U3/D4. Inspect for bridges and rail shorts before powering.

## 4. Power and firmware

Keep the vehicle disconnected. Use a current-limited supply through J1; 13.5–14 V may be needed to cross the battery supervisor's restart threshold. Verify polarity and connector pin numbering.

A portable firmware setup from the repository root needs Python, a C++17 compiler for tests, and PlatformIO:

```sh
python3 -m venv .venv
.venv/bin/python -m pip install platformio==6.1.18
python3 firmware/leaf-heat/tests/run_host_tests.py
.venv/bin/pio run -d firmware/leaf-heat
```

The project pins Espressif32 6.12.0. Without local settings the image has empty credentials and CAN writes disabled. Copy `include/settings.example.hpp` to `include/settings.hpp` within the firmware directory; enter Wi-Fi credentials and a separate control key of at least 12 characters. Keep CAN disabled during commissioning. Never publish settings or configured binaries.

Use **3.3 V logic UART**: adapter TX → J3 pin 2, RX → pin 3, GND → pin 1. Leave adapter power disconnected. Power the board before connecting UART; remove UART before board power. Follow [firmware instructions](../firmware/leaf-heat/README.md) for BOOT/RESET and flashing.

## 5. Bench, network and vehicle tests

Measure regulation/ripple, cutoff/recovery, ADC accuracy and parked current. Attach the external antenna before Wi-Fi use. Reserve the IP address; use the same LAN without guest isolation. Test router restarts and weak signal for at least 24 hours, including absence of stale commands.

Test a properly terminated two-node CAN bench network first. Verify [cable continuity and vehicle/TCU profile](../hardware/rev-g/VEHICLE-WIRING.md). Only afterward explicitly enable CAN writes and test beside the car. Observe On/Off, local timeout and the car's own timeout. Transmit success does not prove heating.

## 6. Case

Use the STLs under `enclosure/rev-g-v2/print/`; Blender source and generator are included. PCB/component meshes are references, not printable parts. Read the enclosure guide for scale, fasteners, material, fit coupons and antenna strain relief. G.5 retains the checked G.3 mechanical geometry, with compatibility records. Physical fit and hot-car suitability remain unverified.

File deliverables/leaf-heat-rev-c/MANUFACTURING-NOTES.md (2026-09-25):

# Leaf Heat Rev C — quotation and prototype assembly

**Use Rev C files only. This is an untested engineering prototype, not a vehicle-qualified production release.**

Request prices for one and two fully assembled boards. A supplier's minimum batch of five blank boards is acceptable for quotations only. No purchase, paid procurement or manufacturing authorization accompanies these files.

## Fabrication

- Rectangular PCB: **65 × 50 mm**, four layers, nominal **1.6 mm FR-4**.
- Layer order: F.Cu / In1.Cu GND / In2.Cu 3.3 V + GND / B.Cu.
- **Standard factory stackup; controlled impedance: NO.** There are no USB data pairs or board-level RF feedlines. The Wi-Fi antenna and matching are inside the purchased module. The old Rev B 90 Ω ±10% USB requirement is superseded for this revision.
- Copper: **1 oz outer and 1 oz inner**, retained from Rev B. Do not substitute thinner inner copper without a separate design decision. Standard green mask, white silkscreen and lead-free HASL.
- No blind or buried vias. Standard signal/ground vias are 0.65 mm diameter with 0.30 mm drill. The drill report also contains package-specific 0.33 mm thermal holes and connector/mounting holes.
- Routed track minimum: 0.20 mm. Global minimum clearance: 0.15 mm; normal net-class clearance: 0.20 mm. Copper-to-board-edge minimum: 0.30 mm. Use the supplied design and drill files, not these summary numbers to reconstruct geometry.
- The CAD dielectric dimensions are nominal visualization values, **not a request for a custom laminate**. Preserve layer order and nominal overall thickness. Report any DFM adjustments before fabrication.

## Assembly

**Fit all 41 BOM components on the top: 39 SMT plus J1 and J3 through-hole connectors.** No DNP components are included. No hand soldering is expected from the customer. Three mechanical mounting holes have no purchased parts.

Use exact manufacturer part numbers. Report unavailable parts and proposed substitutions before purchasing them. JLCPCB catalogue IDs are intentionally blank until exact MPN matching is performed; do not reuse the old Rev B auto-matches or manufacture with missing components.

J1 is NorComp **182-009-113R531**, male DB9. J3 is Harwin **M20-9990346**, three contacts on 2.54 mm pitch, 0.64 mm square pins. J3's finished plated-hole nominal diameter is 1.00 mm. It uses ground thermal reliefs for soldering. Both connectors must be installed from the top.

U4 retains the part number **USBLC6-2SC6** but now protects **UART signals**. It is not a USB controller or a reason to quote impedance control. C14 is now **100 nF**, MPN GRM188R71C104KA01D; do not populate the old 1 µF part from Rev B.

Review exposed-pad soldering and solder wicking at the regulator and ESP32 module. Their footprint thermal holes are plated but not specified as filled/capped via-in-pad; normal tenting does not guarantee filling. Confirm an appropriate stencil/reflow process and report if extra processing is required. Do not silently add a costly via-fill process to the quote.

The radio antenna and DB9 body overhang the board. Keep the antenna area free of panel tabs, fixtures and conductive enclosure material; allow for overhang during assembly support. The DB9 3D model is approximate. Confirm mechanical dimensions with the exact part drawing before an enclosure is finalized.

## Coordinates and files

Gerber, drill and placement origin is the **lower-left board corner**. Placement X increases right; Y increases up. All rotation values come from the saved KiCad board.

**J1 and J3 footprint origins are at pin 1, not their body centroids.** Interpret these two placement rows using the assembly drawing and exact connector drawings. Component rotations and polarized parts must be reviewed in the manufacturer's placement preview before confirming assembly. The CSV is not a promise that every vendor's rotation convention will match automatically.

- `leaf-heat-rev-c-gerbers.zip`: four copper layers, mask, silkscreen, paste, outline and separate plated/non-plated drills.
- `BOM-PCBWay.csv` or `BOM-JLCPCB.csv`: exact purchasing list, 25 MPN groups / 41 placements.
- `placements.csv` or `CPL-JLCPCB.csv`: 41 component positions; mounting holes excluded.
- `placement.png`, `schematic.png`: assembly/circuit review drawings.
- `leaf-heat-v3-ipc2581.xml`: supplementary native manufacturing export, not a replacement for the agreed Gerber/BOM workflow.

No firmware, Wi-Fi credentials, customer address, vehicle identifiers or factory functional-test program is included. Quote assembly, all components, sourcing/MOQ/attrition, stencil/setup, both through-hole connectors, shipping to Norway, and taxes separately. A quote for bare PCBs or assembly labour alone is incomplete.

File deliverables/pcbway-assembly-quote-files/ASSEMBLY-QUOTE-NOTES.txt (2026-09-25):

QUOTATION ONLY — LEAF HEAT REV A

Please quote supply and assembly of 1 board from a batch of 5 bare PCBs.
47 components per assembled board: 46 SMT and one through-hole DB9 connector J1; 29 distinct manufacturer part numbers. All component bodies are on top.
BOM quantities are PER BOARD. Quote all parts, procurement attrition/minimum order costs, stencil/setup, reflow and through-hole soldering, PCB fabrication and shipping to Norway.
Use the exact specified manufacturer part numbers for this quote. Obtain approval before substitutions.
USB J2 is an SMT connector with through-hole anchors; include soldering these anchors.
ESP32 antenna extends beyond the PCB outline. Please review panel handling clearances and the exposed-pad/module thermal-via paste and solder-wicking requirements.
Placement coordinates are millimetres, top side, KiCad rotations, lower-left drill/place origin. J1's placement origin is signal pin 1, not the body centroid. Verify all component orientations before assembly.
The preview uses approximate connector models; the BOM and Gerbers govern the quote.
No firmware or functional test procedure is supplied. No cable or enclosure is included.
The design is an untested engineering prototype. Quotation and manufacturability review only; do not start fabrication or assembly without a separate approved order.

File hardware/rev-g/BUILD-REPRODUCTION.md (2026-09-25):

# Rev G sources and reproducibility

Use the supplied native KiCad files and matched ZIPs for this checked revision. They are the authoritative reviewed artifacts; scripts are engineering generators, not a one-click production release system.

Generation sequence:

1. `build_rev_g.py` copies the preserved Rev F source, adds the new circuitry and critical regulator routes.
2. `route_rev_g.py` adds plane fanouts. `prepare_router.py` prepares the external-router DSN. The local Freerouting session is in `exports/leaf-heat-v7.ses`; it was imported using KiCad's native `ImportSpecctraSES` function.
3. `finish_rev_g.py` completes the fine-pitch escapes. `finalize_values.py` applies the final precision resistors, 10 µF delay caps, taped C15 ordering part, and all 27 hand-parts rows on the back. Do not use the builder's intermediate values as the BOM.
4. Run native schematic netlist export/ERC and PCB DRC with copper refill, save-board and schematic parity. Run `audit_rev_g.py`, `analyze_protection.py` and `export_rev_g.py` with the KiCad Python runtime. The audit reads both native revisions; it does not modify them.
5. `make_shopping_list.py` regenerates the final target quantities. Live basket availability/prices are a separate verification step and cannot be inferred from this script.
6. `package_rev_g.py` checks native hashes against the audit and packages the final Gerbers, BOMs, placements and review files. If any native file changes, regenerate all dependent exports, audits and packages.

Python runtime: `tools/KiCAD-MCP-Server/venv/bin/python3`, with KiCad 10.0.6. CLI: `/Applications/KiCad/KiCad.app/Contents/MacOS/kicad-cli`. Set `FONTCONFIG_FILE` to the repository's `hardware/fontconfig.xml`. The Freerouting jar/JRE are under `tools/freerouting`; router results may vary by runtime/version and must receive a fresh native DRC after import.

Rev G.1 is a targeted metadata-only U5 substitution. `apply_u5_g1.py` is a one-time migration that archives the preceding release; do not rerun it. `audit_u5_g1.py` proves full parsed native equivalence after the exact identity/datasheet change and verifies the unchanged hand BOM and native placement CSV, and the explicit JLC catalogue rotation offsets. Run it after exports and include its report in the packages. The builder also now specifies the new U5.

The enclosure has separate geometry/hash checks described in its README. Physical PCB changes require refreshing its GLB reference and native geometry hash before rebuilding the Blender model. For G.1, the complete geometry-equivalence audit permits reuse of the original model, recorded in `enclosure/rev-g-v1/compatibility-g1.json`; original render provenance is retained. Firmware has its own pinned build configuration and host tests.

Historical intermediates and logs under `exports/` are retained for investigation. Only the five ZIPs listed in `deliverables/README.md` are the current board handoff packages. No assembler DFM approval or physical qualification is implied by reproducibility or matching hashes.

## G.2 layout and silkscreen update

`history/rev-g1-before-adi-g2.zip` preserves the complete pre-change source and outputs. `apply_adi_g2.py` applies the approved edits to that exact G.1 PCB only. The native files include the G.2 changes and subsequent G.3 antenna overlay; do not rerun historical migrations.

For the historical G.2 build only: export the schematic XML netlist, run ERC, and run KiCad PCB DRC with `--refill-zones --save-board --all-track-errors --schematic-parity --severity-all`. Keep the 1.0 mm text / 0.15 mm stroke / 0.15 mm silk-clearance rules. On this Mac the refill/save operation needs access to macOS display services; the sandbox-only run can abort. Then run `export_rev_g.py`, `export_pin1_reference.py`, `audit_rev_g.py`, `audit_adi_g2.py`, and `package_rev_g.py` in that order. The G.2 packager wrote `rev-g2` names; those outputs are now archived. Use the G.3 process below for current files. The historical `audit_u5_g1.py` compares G.1 only and is not the current layout audit.

G.2 geometry compatibility with the existing enclosure is recorded in `enclosure/rev-g-v1/compatibility-g2.json`. Do not overwrite the original render hashes with a new board hash without rebuilding the reference.

## G.3 antenna update

`apply_antenna_g3.py` is a one-time overlay for the exact archived G.2 PCB, not a general rebuild command. Current native files already include it. Use `export_rev_g.py`, `make_shopping_list.py`, fresh ERC/netlist/DRC with refill, `audit_rev_g.py`, `audit_antenna_g3.py`, and `export_pin1_reference.py` for current exports/checks. `audit_adi_g2.py` remains a historical G.2 audit and must not be relabelled as a G.3 check. `package_rev_g.py` requires current G.3 audit hashes. Rebuild the new enclosure under `enclosure/rev-g-v2` from the current PCB GLB.

## G.4 top-side tenting update

`apply_tenting_g4.py` is the one-time overlay against the immutable `history/rev-g3-before-tenting.zip` G.3 baseline. Current files already include it. Do not rerun historical migrations. Run fresh ERC/netlist and PCB DRC with refill/save/parity, then `export_rev_g.py`, `export_pin1_reference.py`, `audit_rev_g.py`, `audit_tenting_g4.py` and `package_rev_g.py`. The current packager requires the G.4 audit hashes. `audit_antenna_g3.py` is now historical. Do not overwrite its old report as if it checked G.4.

The Gerber audit uses gerbonara 0.13.0, shapely 2.0.7 and NumPy 1.26.4 installed in the repository's KiCad Python environment. It parses final positive mask/paste Gerbers independently, evaluates hole coverage/open bottom ends and stencil area, compares native geometry and electrical fabrication plots against G.3, and makes the enlarged review drawing. The supply basket is unchanged and must not be regenerated with its live extras removed. Firmware and enclosure geometry are unaffected; see the enclosure's G.4 compatibility record.

## Current G.5 release

`history/rev-g4-before-filled-g5.zip` preserves the G.4 input with verified per-file hashes. `apply_filled_g5.py` is a one-time mask/process/branding migration; do not rerun it on the already revised PCB. The audit was run before the migration and failed on the G.4 mask tents, then passed after the change. No copper/drill/part/placement changes are permitted by this revision.

For current outputs: fresh netlist/ERC and DRC with refill/save/parity; `export_fill_g5.py`; `export_rev_g.py`; `export_pin1_reference.py`; `audit_rev_g.py`; `audit_filled_g5.py`; then `package_rev_g.py`. All commands use the KiCad Python environment above. The new packager requires G.5 audit hashes. Older G.1–G.4 audits/migrations are historical only. `verify_mouser_export.py` is a historical live-cart script: do not run it to overwrite the received-parts basket with obsolete assumptions.

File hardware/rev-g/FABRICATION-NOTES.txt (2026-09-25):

LEAFY REV G.5 — EPOXY-FILLED AND COPPER-CAPPED THERMAL HOLES

100 x 100 mm finished PCB, 4 layers, 1.6 mm FR-4, 1 oz outer AND inner
copper, green mask, white silk, lead-free HASL. Five PCBs; assemble TWO.
Select Epoxy Filled & Capped and Horizontal Electroless Copper Plating.

REQUIRED FILL/CAP: six 0.33 mm thermal PTHs under U1 and twelve 0.30 mm
thermal PTHs under U2, ALL 18 PER PCB. Include U1's 0.33 mm holes even
though they exceed the default 0.30 mm selection. These are thermal vias,
not component-lead holes. Locations: THERMAL-FILL-LOCATIONS.csv / drawing.
Epoxy fill, planarize and copper-cap both ends; top surface solderable.
Normal eligible signal vias may follow the selected JLC filling process.
Leave component-lead, connector, test and mounting holes open.

The top thermal mask openings are continuous; there are NO local mask
covers over these 18 holes. The bottom mask exposes the capped annuli;
it does NOT request open barrels. Preserve the supplied pad/mask/copper
geometry. Solid thermal-plane connections are intentional; do not replace
these with thermal-relief spokes. This revision replaces all G.4 tenting,
mask-cap-survival and exact-stencil instructions.

STANDARD PCBA, TOP ONLY: fit exactly U1/U2/U4/U5/U6/L1 per matching BOM/CPL.
Use JLC's normal component-library stencil engineering, considering the
actual solder-mask-defined pads. SPECIAL STENCIL = NO. The supplied paste
layer is reference only, NOT an exact-aperture or thickness requirement.
No step stencil, custom stencil file or paste on unpopulated pads requested.
Solder U1's exposed pad; control U2 paste to avoid lifting its outer leads.
Use normal assembly inspection; no custom inspection report requested.

Add necessary temporary assembly rails/fiducials externally, preserving the
100 x 100 mm finished outline, mounting holes and connector clearances.
Remove assembly rails before delivery. Apply supplied JLC CPL angles once;
retain manual PCB production-file and placement confirmation.
DO NOT power/program the incomplete boards. ANT1 is customer plug-in.

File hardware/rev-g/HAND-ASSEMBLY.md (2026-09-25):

> G.5 update: the board is named Leafy. All hand parts and wiring are unchanged. U1/U2 thermal holes are factory epoxy-filled and copper-capped; do not drill them out. The Mouser parts already received remain compatible.

# Rev G.3 — hand-assembly guide

The factory fits **U1, U2, U4, U5, U6 and L1**. Fit the remaining **49 parts** using `BOM-HAND.csv` and the assembly map. The parts-value table is printed on the back to leave room between the top-side components. Every component mounts on the top. Only through-hole solder joints are made from the underside.

This is still an SMD project. The larger 1206 resistors/capacitors are 3.2 × 1.6 mm, with pads extending beyond their ends. U3 and D4 remain the hardest hand-fitted parts, but both have visible leads and extended pads. Practise with spare 1206 parts and a spare SOIC/SOT-23 board first.

## Equipment

A temperature-controlled iron with a small chisel tip, fine electronics solder, electronics flux, tweezers, magnifier, solder wick, board holder and multimeter are appropriate. Use ventilation and eye protection when clipping leads. Avoid plumbing/acid flux. Extra resistors and capacitors are inexpensive insurance against losing a part.

Use a short, controlled heating time following the component maker's hand-solder guidance. Heat the pad and terminal together. More pressure or prolonged heating is not a substitute for a clean, correctly sized tip. In particular, do not thermally shock ceramic capacitors or lever components against the board. Let a stubborn joint cool before another attempt. A ground pad may take slightly longer because it connects to a plane.

For each two-terminal SMD component: apply flux, lightly tin one pad, hold the component with tweezers, reheat that pad and slide the part into alignment. Let it cool, then solder the other end. Inspect both ends. Do not bridge the gap underneath with solder.

## Parts and orientation

| Parts | Orientation/check |
| --- | --- |
| R1–R10, R18–R20 | Resistors are not polarized. Check the value with the list/meter before fitting; R2 is **43.2 kΩ**, not 43 kΩ or 47 kΩ. |
| C1–C14, C16–C20 | Ceramic capacitors are not polarized. Their values usually are not printed. Keep each value in its labelled bag. C1/C2 need **100 V** ratings. |
| C15 | Polarized radial 47 µF / 63 V capacitor. Positive lead to square pad 1 / BULK_DAMPED; negative stripe to round pad 2 / GND. Fit it upright and trim its leads. |
| R21–R26 | R21 is 1 Ω pulse-resistant 2512. R22/R23 are precision 680 kΩ / 47 kΩ, 0.1%; do not mix R23 with R8's 1% 47 kΩ part. R24 = 10 MΩ, R25 = 470 kΩ, R26 = 100 kΩ. |
| F1 | 1 A fuse; either orientation. Never bridge it with wire or solder. |
| D1 | B1100-13-F, polarized 100 V / 1 A Schottky diode. Package cathode band goes to pad 1 / board cathode line / VPWR. This replaces the unverified SS110-13-F ordering entry. |
| D3 | SMBJ24CA is bidirectional; either orientation. Do not substitute the unidirectional SMBJ24A without review. |
| D6 | Green LED. Match the package cathode marking to **K** / pad 1 on the PCB. |
| U3 | TCAN3404DRQ1 SOIC-8; pin 5 is SHDN and is grounded on Rev G. Do not use the old TCAN3403 part here. Align pin 1 with the board's pin-1 marker; inspect all eight leads for bridges. |
| D4 | PESD2CAN,215. Three-pin SOT-23; match the two-lead side and single-lead side to the footprint. Pin 3 is GND. |
| SW1/SW2 | C&K PTS645SL43-2 LFS, four through-hole legs. Legs come in electrically common pairs; verify the unpressed switch does not short its two contact groups. |
| J1 | Exact NorComp 182-009-113R561, male DB9 with 4-40 female screwlocks. Check that the cable seats fully and its screws engage without force. Solder nine pins and both shell anchors. The anchors need more heat. |
| J3 | Three-pin header. Square PCB pad is pin 1, GND; the board labels read GND / RX / TX. |

There is **no component** to fit at TP1–TP7; these are bare test holes.

## Assembly sequence

1. Inspect the delivered board and factory-fitted parts. Confirm U1, U2, U4, U5, U6 and L1 are fitted correctly and no hand positions were populated unexpectedly. Obtain the factory's exposed-pad inspection result where available.
2. With power and programmer disconnected, fit the low SMD parts: resistors, capacitors, fuse, diodes and LED. Work one value at a time, checking each reference against the parts list. The regulator's nearby parts must sit directly on their pads; do not extend them on wires.
3. Fit U3 and D4. Tack one corner lead, align, then solder the remaining visible leads using flux. Inspect for bridges under magnification; use solder wick to remove excess.
4. Fit the through-hole buttons, then C15, J3 and J1. Keep the parts seated and solder every intended terminal. Fit the buttons after any cleaning because PTS645 switches are not washable.
5. Inspect every hand joint and compare the completed board against the full assembly map. Check polarity and resistance/capacitance values again. Check that the two button contact groups are open when unpressed and close only while pressed.
6. With all supplies disconnected, check for accidental shorts between GND and CAR_12V, VPWR and 3V3, and between adjacent U3 leads. Capacitors can briefly look like low resistance while charging from a meter; a continuity beep alone is not a complete diagnosis.

Check U3 pin 5 has continuity to GND and no direct short to 3V3. Check C13 remains across 3V3 and GND; it must not bridge onto U3 pin 5.

## External antenna

Fit ANT1 (Molex 1461530300) to the factory-fitted **ESP32-C3-WROOM-02U-N4** before powering Wi-Fi. It is a plug-in part; no soldering. With power disconnected, align the U.FL plug squarely, press the connector straight down and leave a slack cable loop. Use the enclosure v2 exit and securing saddle. See [antenna mounting](ANTENNA-G3-CHANGE.md).

## First power and programming

Complete all hand assembly before power: the factory's six components alone do not make a working regulator. Keep the vehicle disconnected.

Use a regulated **13.5–14 V bench supply with current limiting**, connected through J1 pin 9 (+) and pin 3 (GND). Verify these pins by continuity to the labelled test points, not by counting the mating face from memory. Start with ESP_EN held low through TP7 to TP1/GND. Begin with a low current limit and watch the supply; stop if current stays unexpectedly high or a part heats. Current-limit settings and startup behaviour need bench qualification, so do not repeatedly increase the limit to force a faulted board to start.

Measure CAR_12V, VPWR and 3V3 relative to TP1. The protected input is below the input supply by D1's forward drop. The expected nominal output is about **3.315 V**. The earlier **3.22–3.41 V** calculation covers reference and resistor tolerances only; it is not a complete pass/fail window. TI's light-load PFM regulation allowance gives an estimated upper value of about **3.446 V** after resistor tolerance. Investigate an unexpected reading before releasing reset. Verify startup, ripple and load changes with an oscilloscope: the ESP32 supply must remain within its **3.0–3.6 V operating range**, including peaks. A meter reading alone does not establish this. See the [review](DESIGN-REVIEW.md) and [regulator datasheet](https://www.ti.com/lit/ds/symlink/lmr36510.pdf).

Release the EN short only after the rail is verified. A radio startup can draw more current than the reset-held state, so use the measured behaviour to set a suitable limit. Check the supply under radio activity before any car connection.

Program using a **3.3 V logic UART adapter** and the separate 12 V supply; J3 provides no power. Adapter TX goes to board RX, adapter RX to board TX, and grounds connect. Insulate the adapter's power lead. Hold BOOT, press/release RESET, then release BOOT to enter download mode. Firmware offsets and build instructions must come from the actual firmware project; firmware source and build instructions are supplied in ../../firmware/leaf-heat/README.md; CAN writing is locked by default. See [programming](../../firmware/leaf-heat/README.md).

## Test-point map

| Ref | Net | Purpose |
| --- | --- | --- |
| TP1 | GND | Meter/bench ground |
| TP2 | CAR_12V | Incoming power, before fuse |
| TP3 | VPWR | Protected supply after fuse and diode |
| TP4 | 3V3 | Regulated output |
| TP5 | CAN_H | CAN high measurement; avoid accidental shorts |
| TP6 | CAN_L | CAN low measurement; avoid accidental shorts |
| TP7 | ESP_EN | Reset/enable; pull to GND to hold the radio in reset |

The first vehicle connection still requires verification of the exact Nissan cable, safe firmware behaviour, CAN standby, low-battery handling and parked current. U5 supplies independent battery cutoff; measure its actual shutdown and recovery thresholds before leaving the board connected.

U5 delays initial startup until VPWR is above its recovery threshold. Start with 13.5–14 V on the current-limited bench supply, then measure the actual threshold. Do not short BUCK_EN to bypass protection. C18/C19 are both **10 µF**, not 1 µF. The factory-fitted U5/U6 are fine-pitch parts; leave their solder joints undisturbed.

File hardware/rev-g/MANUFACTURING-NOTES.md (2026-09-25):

# Leafy G.5 — fabrication and Standard partial assembly

Use only the matching `leafy-rev-g5` packages. Order **five PCBs and two Standard top-side assemblies**. The finished board remains 100 × 100 mm, four layers, 1.6 mm FR-4, 1 oz outer **and inner** copper, green mask, white silk, lead-free HASL.

## Fabrication

Select **Epoxy Filled & Capped** and **Horizontal Electroless Copper Plating**. The 18 mandatory filled/capped thermal holes are six 0.33 mm under U1 and twelve 0.30 mm under U2 on every PCB. U1's 0.33 mm holes must be included explicitly. The exported hole-location CSV and drawing identify them independently of KiCad's PTH-pad classification. Other eligible signal vias can follow JLC's normal fill process. All component-lead, connector, test and mounting holes must remain open.

Retain the plated barrels and solid ground connections; epoxy filling does not replace the conductive barrel. Both ends are capped; the top is a flat solderable pad. The bottom mask opening exposes a capped annulus, not an open barrel. Preserve the top solder-mask-defined pad boundaries (U1 2.71 × 3.40 mm; U2 2.70 × 2.70 mm). G.5 removes the G.4 local mask tents. No solder-mask cap survival requirement remains. Do not add thermal-relief spokes to the thermal pad/via heat paths.

## Assembly

Factory-fit exactly these parts; quantities are one each per assembled board:

| Ref | MPN | JLC/LCSC |
| --- | --- | --- |
| U1 | LMR36510ADDAR | C1858393 |
| U2 | ESP32-C3-WROOM-02U-N4 | C2926676 |
| U4 | USBLC6-2SC6 | C7519 |
| U5 | TPS3760A012DYYR | C5218894 |
| U6 | TMUX1511PWR | C2866750 |
| L1 | SRN6045TA-220M | C2044314 |

**Special stencil: No.** JLC's normal engineering process selects stencil thickness and apertures using its component library, the actual revised PCB pads and component assembly guidance. Native/exported paste is reference geometry only. There is no required 0.125 mm thickness, exact aperture pattern, user-specified stencil file, step stencil, or paste printing for the 49 unpopulated hand-fitted parts. U1's exposed thermal pad must be soldered. U2 paste volume must avoid lifting the module and compromising perimeter joints. Use normal JLC inspection; no special report is requested.

Use the exact BOM without substitutions. `CPL-FACTORY-JLCPCB.csv` already contains the catalogue rotation corrections: do not apply them twice. Verify the new order's six placements against the pin-one coordinate CSV and assembly drawing. A historical G.4 viewer check is not approval of the new order.

Choose JLC-added temporary assembly rails/fiducials and rail removal before delivery. The finished outline must remain 100 × 100 mm; component/connector locations and mounting holes are unchanged. Let JLC determine its panel tooling, preserving all finished-board clearances. Review the processed board and placement preview before release.

The customer solders the other 49 components per board and plugs in ANT1. Do not populate bare test/mounting holes, supply substitutes or power/program the incomplete assembly.

## Status

The files are prepared for a new Standard order. They do not prove physical hole filling, solder-joint quality or vehicle operation. The supplier performs fabrication/assembly review; bench testing follows hand assembly. Old order PRIVATE-RECORD-REMOVED cancellation/refund has not been verified here. Do not reuse the old G.4 order files.

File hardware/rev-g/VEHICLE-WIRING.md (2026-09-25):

# Rev G vehicle wiring and firmware interface

This guide applies to the **100 × 100 mm custom Rev G board**. The earlier development-board plan has different GPIO assignments. Buildable prototype firmware is supplied in [firmware/leaf-heat](../../firmware/leaf-heat/README.md), with CAN writing disabled by default. Complete hand assembly and bench tests before vehicle connection.

## Cable, identified by numbered contacts

Use the exact Nissan OVMS cable pinout below. Board J1 is a male DB9; the cable end is female. Check continuity with the cable unplugged at both ends. Do not identify pins by wire colour or a mirrored connector drawing.

| Vehicle OBD-II contact | Cable DB9 / board J1 contact | Rev G function |
| --- | --- | --- |
| 16 | 9 | CAR_12V, through F1 and D1 |
| 4 | 3 | GND |
| 13 | 7 | EV-CAN high |
| 12 | 2 | EV-CAN low |
| 6 | 5 | Alternate CAN high; **not connected on this PCB** |
| 14 | 4 | Alternate CAN low; **not connected on this PCB** |

J1 contacts 1, 6 and 8 are also unconnected. The two PCB connector shell anchors connect to GND. The specified cable mapping is published by [OpenEnergyMonitor](https://shop.openenergymonitor.com/nissan-ze0-e-nv200-obd2-ovms-cable/). A generic OBD/DB9 cable is not interchangeable merely because it fits.

## Confirm the vehicle profile

The intended profile is the **2013–2015 EV-CAN remote-climate implementation**. The owner remembers disconnecting the original TCU when installing OVMS. This supports the profile but must be checked physically before CAN writes are enabled. Registration in 2015 and the registration document's ZE0 label alone do not establish the TCU generation. Record the vehicle build/model year and fitted TCU before enabling transmissions.

OVMS instructs owners of the applicable 2013–2016 configuration to disconnect the original TCU's large white plug if fitted. Its 2016–2017 instructions instead isolate TCU CAN while retaining other connections for the hands-free microphone. Follow the instructions matching the actual vehicle. See [OVMS installation guidance](https://docs.openvehicles.com/en/latest/components/vehicle_nissanleaf/docs/index.html#remote-climate-control).

**Rev G cannot select the alternate bus in software.** It has one transceiver connected to J1 pins 2/7; pins 4/5 go nowhere. A car requiring the later profile needs a reviewed cable remapping or hardware revision as well as different firmware commands. This PCB also lacks the separate activation output used by the earliest cars.

## Firmware GPIO map

| Function | ESP32-C3 GPIO | Module U2 contact | Connected hardware |
| --- | --- | --- | --- |
| CAN transmit | 4 | 3 | U3 TXD, contact 1 |
| CAN receive | 5 | 4 | U3 RXD, contact 4 |
| CAN standby | 1 | 17 | U3 STB, contact 8; HIGH = standby |
| Protected-input measurement | 0 / ADC1_CH0 | 18 | R7/R8/C11 divider through U6, with R26 loading |
| Status LED | 7 | 6 | R9/D6; HIGH lights LED |
| UART receive | 20 | 11 | R19, U4, J3 pin 2; adapter TX |
| UART transmit | 21 | 12 | R18, U4, J3 pin 3; adapter RX |
| BOOT | 9 | 8 | SW2; held LOW during reset for download |

GPIO2 and GPIO8 have pull-ups. EN has a 10 kΩ / 1 µF reset network and SW1. These module pin functions and boot straps match [Espressif's module datasheet](https://www.espressif.com/sites/default/files/documentation/esp32-c3-wroom-02_datasheet_en.pdf). J3 carries **3.3 V logic and ground only**; use [firmware instructions](../../firmware/leaf-heat/README.md).

U3 is TCAN3404DRQ1. Its SHDN pin 5 is permanently grounded; the controller continues to use STB pin 8. C13 remains an extra 3V3 bypass, while C12 is the short local VCC bypass.

R10 holds CAN standby high during reset. Firmware must keep standby high until the CAN controller is initialized with a recessive TX state; then use LOW for normal CAN operation. Use 500 kbit/s classical CAN, 11-bit identifiers. The board adds no termination; a separate two-node bench network needs its own correct termination. Check STB, TX and the bus during reset, flashing and crashes. The transceiver mode/pinout is documented by [TI](https://www.ti.com/lit/gpn/TCAN3404-Q1).

The battery divider reads **VPWR after the fuse and diode**, not raw battery voltage. With U6 enabled, R26 loads R8: the nominal multiplier is 32.2766; at VPWR = 12 V the ADC node is about 0.372 V. Calibrate against a meter at J1 and allow for changing diode drop. Configure the ADC range explicitly and average settled readings. U5 now controls the regulator independently; see DESIGN-REVIEW.md for cutoff/recovery thresholds.

## Narrow protocol specification for the confirmed earlier profile

The implementation follows the source-verified sequence below. It has host tests and a successful build, but no powered CAN/vehicle test yet:

| Action | Standard CAN frame | Timing |
| --- | --- | --- |
| Wake before On or Off | 0x679, DLC 1, `00`; then 0x5C0, DLC 8, all zeros | Once per action |
| On | 0x56E, DLC 1, `4E` | 24 sends, 100 ms apart |
| On completion | 0x56E, DLC 1, `46` | One second after the 23rd On repeat, about 3.3 s after starting |
| Off | 0x56E, DLC 1, `56` | 24 sends, 100 ms apart, after wake |

Verified against `SendCommand`, `RemoteCommandTimer`, `CommandWakeupAZE0`, `RemoteCommandHandler` and timer initialization in [OVMS revision 85074a0](https://github.com/openvehicles/Open-Vehicle-Monitoring-System-3/blob/85074a0ae7a983b308c6e2e081185492527ee073/vehicle/OVMS.V3/components/vehicle_nissanleaf/src/vehi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), with the repeat count in its [header](https://github.com/openvehicles/Open-Vehicle-Monitoring-System-3/blob/85074a0ae7a983b308c6e2e081185492527ee073/vehicle/OVMS.V3/components/vehicle_nissanleaf/src/vehi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). The first timer-driven command is approximately 100 ms after wake; the count is 24 total in this implementation despite the header comment's wording.

The application serializes requests and is designed to cancel stale completion timers when Off is requested, stop bounded retries on errors, and never replay an old On command after a reset or Wi-Fi reconnection. Initially prove receive-only operation. Report request sent separately from confirmed climate operation. Validate actual heating and stopping on this car; these frames request the vehicle's climate function and do not directly switch or select the heater element.

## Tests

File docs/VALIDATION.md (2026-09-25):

# Validation status — 25 September 2026

**Manufacturing files reviewed; physical prototype not yet validated.**

| Area | Evidence / status |
| --- | --- |
| CAD | Saved G.5 ERC/DRC: zero reported violations, unconnected items or schematic mismatches under configured rules, with refill/parity checks |
| Native audits | 55 components, pin/net mapping, factory scope and fabrication output comparisons |
| G.5 compatibility | Copper, nets, drills, placements, BOM and mechanical geometry unchanged from G.4; mask/process/branding changed |
| PCB CAM | Original drill locations, connectivity, continuous thermal-pad mask openings, all 18 fill locations including 0.33 mm, temporary rails reviewed |
| Final placement | Six exact MPNs, centres, lead alignment and pin-one directions checked in final viewer; two top-side partial assemblies |
| Firmware | Recorded ESP32-C3 build; 25 behavioral host tests; no physical device execution claimed |
| Enclosure | Mesh/geometry checks and G.5 compatibility; no printed fit/environmental test claimed |
| Physical operation | Supply/transients, parked current, RF, CAN and heater operation **not yet tested** |

See [design review](../hardware/rev-g/DESIGN-REVIEW.md) and [firmware fixes](../firmware/leaf-heat/verification/REVIEW-FIXES.md). Reports identify exact inputs; changes require relevant checks again. A zero CAD report is not proof of reliability.

## Next milestones

1. Inspect incoming factory joints and thermal-pad work; finish hand assembly, check orientation/bridges/rail resistance.
2. Current-limited first power, vehicle disconnected. Measure 3.3 V regulation, startup, ripple and Wi-Fi bursts; check input hot-plug behavior with suitable instruments.
3. Measure cutoff/recovery thresholds and delays at VPWR and the input. Calibrate ADC; measure shutdown, connected and router-loss current.
4. At least 24-hour Wi-Fi test with router restart, DHCP renewal and weak signal; check actual antenna location.
5. Correctly terminated two-node CAN bench test: reset/standby, arbitration, missing ACK, bus-off and pending-frame cancellation.
6. Confirm actual model/TCU and unplugged cable continuity. Enable CAN only after bench checks, then observe On/Off, timeout, repeated sessions and network loss beside the car.
7. Verify the vehicle's own timeout and consequences of board power loss; do not infer success from frame transmission.
8. Check printed case, cable fit, antenna strain relief and intended environmental conditions.

Record test date, hardware revision, firmware commit/non-secret settings, instruments, wiring, supply/temperature, expected/measured results and pass/fail. Save traces/photos without private identifiers.

No ISO 7637/16750, EMC, completed-device radio, ingress or automotive qualification is claimed.

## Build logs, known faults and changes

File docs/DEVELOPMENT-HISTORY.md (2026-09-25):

# Development history

This records engineering decisions and outcomes, not private conversations. Earlier documents retain their historical context and must not be used as G.5 manufacturing instructions.

| Stage | Change and reason |
| --- | --- |
| Research | Compared complete OVMS, 4G modules and custom approaches; established that the vehicle integration is more than a modem |
| Narrowed scope | Home Wi-Fi, climate On/Off only, because Wi-Fi reaches the parking location |
| A | Initial compact two-layer custom board with USB programming |
| B | Four-layer placement/plane/routing revision after layout review |
| C | Replaced USB-C/power with three-pin UART to reduce complexity/cost; separate programmer and supply required |
| D | 150 × 150 mm board, larger passives and accessible pads; four difficult parts factory fitted |
| E | 100 × 100 mm, more useful hand-solder spacing; corrected D1 purchasing code |
| F | Mouser-compatible CAN chip, DB9 and output capacitors; U3 pin 5 changed to ground for TCAN3404 |
| G | RC input damping, independent battery cutoff, powered-off ADC isolation, closer regulator components and different buttons |
| G.1 | Stocked TPS3760A012DYYR supervisor; documented the lost automotive qualification/earlier overvoltage allowance |
| G.2 | Routing and silkscreen cleanup after Adi's review |
| Firmware review | Fixed low-battery protection re-arming, bounded normal CAN retries and transceiver startup timing; expanded to 25 host tests |
| G.3 | External-antenna module, Molex antenna and enclosure cable exit/strain relief; GPIOs unchanged |
| G.4 | Explicit top-side mask tents and custom paste discussion to address thermal-hole solder wicking |
| G.5 | Epoxy-filled/planarized/copper-capped thermal holes, normal library stencil, Standard PCBA and Leafy branding |

## Manufacturing decisions

The final factory scope is **U1/U2/U4/U5/U6/L1**, with 49 other components per board hand-fitted. U3 and D4 still need careful soldering; this is not a through-hole-only beginner kit.

Selecting “Tented” in a quote did not by itself cover holes represented as through-hole pads. G.4 defined mask coverage explicitly, but the supplier could not guarantee the large one-sided tents and warned about ink entering the holes and solder wicking.

G.5 instead requires filling and copper capping **all 18 thermal holes: six 0.33 mm at U1, twelve 0.30 mm at U2**. The 0.33 mm exception must be explicit. Component, test and mounting holes stay open; solid thermal copper connections are intentional.

We removed the exact 0.125 mm stencil and exact-aperture requirements. G.5 accepts JLC's normal component-library stencil engineering, with Special stencil = No. The order uses Standard PCBA. Old tenting, mask-cap-survival and exact-stencil instructions are superseded.

## Review reached on 25 September 2026

Processed PCB artwork was compared with G.5: original drill locations, copper connectivity, continuous thermal-pad mask openings, all eighteen fill locations and temporary rails. The CAM record explicitly included the 0.33 mm holes. Finished size remains 100 × 100 mm after rail removal.

The final engineer-adjusted assembly viewer was reviewed separately. All six exact parts, centres and pin-one directions matched. A uniform +5 mm Y translation corresponds to the panel rail, not a relative placement error. The order specifies two partial assemblies out of five fabricated boards. The owner confirmed the PCB file; the assistant left final assembly approval to the owner after reviewing it.

This does not claim delivery, solder quality, first power-up, RF range or successful heater operation.

## Deferred work and constraints

No common-mode choke was added; this does not establish EMC performance. Low-battery protection takes precedence over Wi-Fi availability. G.5 preserves the already received Mouser part identities. Printed case fit, antenna performance and real supply/CAN/vehicle behavior remain to be tested.

Detailed G.1–G.5 change notes, earlier CAD and firmware review records are preserved. See [validation](VALIDATION.md) for the remaining physical work.

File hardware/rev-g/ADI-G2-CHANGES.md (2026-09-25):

# Rev G.2 — Adi's layout review, 14 September 2026

Historical G.2 change record. Current manufacturing revision is **G.3**; see [external antenna update](ANTENNA-G3-CHANGE.md). The statements below describe G.2. This revision changes routing, two via positions and the silkscreen. Use the new `rev-g2` manufacturing ZIPs together. The saved G.1 JLCPCB quotation contains older fabrication data and must be replaced before ordering; adding an attachment alone does not replace its original Gerber upload.

## Changes

| Reviewed area | G.2 result |
| --- | --- |
| U1/C2 enable via | Verified connected on both layers. BUCK_EN copper is unchanged. C2's reference is moved clear of the crowded area. |
| C10/U2 3.3 V | Removed the redundant triangular route. The supply runs through C10's positive pad to U2 pin 1; existing power-plane vias remain. |
| R19 UART_RX via | Moved from (87.1531, 52.9642) to (89.45, 56.0) mm. Clearance to the adjacent PROG_TX trace increases from 0.2017 to 2.4986 mm. Both layers reconnect. |
| D4 CAN_H test-point via | Moved from (24.95, 82.5) to (26.5, 79.635) mm, directly on the existing CAN_H diagonal route. Clearance to D4's ground pad increases from 0.2406 to 2.0060 mm. The bottom route to TP5 is updated; no extra top-layer branch is introduced. |
| Silkscreen | All 141 visible texts are at least 1.0 mm high with at least 0.15 mm strokes. All 296 silk shapes use at least 0.15 mm strokes. Crowded component references, the LED cathode label and UART labels are repositioned. Both board faces and the schematic identify G.2; the schematic header now lists all six factory parts. |
| Manufacturing rules | Enforce 0.15 mm silkscreen clearance, 1.0 mm text height and 0.15 mm text stroke. Electrical clearance remains 0.20 mm. No new DRC exclusions. |

Dimensions are KiCad coordinates, X right / Y down. They are not CPL coordinates.

JLCPCB publishes the above legend minimums in its [rigid PCB capabilities](https://jlcpcb.com/capabilities/pcb-capabilities). The actual Gerbers subtract solder-mask openings from silkscreen, and the native DRC checks printing clearance before that clipping step.

## Verification

- Fresh copper refill and KiCad DRC with all track errors, all severities and schematic parity: zero violations, unconnected items or mismatches. ERC: zero violations.
- [Independent 55-component electrical audit](exports/independent-audit.json) and [G.1-to-G.2 comparison](exports/adi-g2-audit.json).
- All 66 footprint cores (55 purchased components, seven test points and four mounting holes), pads, models, circuit connections, board outline, zone definitions and antenna keepouts agree with G.1. Only the specified 3V3/UART_RX/CAN_H routes and two via positions change.
- Factory BOM, Mouser hand BOM, shopping quantities, all native placement coordinates and corrected JLCPCB CPL are unchanged. Six factory parts and 49 hand parts per board; two-board hand basket remains 27 SKUs / 98 pieces. No component substitution or new purchase is required.
- Gerbers, drill files, schematic drawings, assembly images and packages are regenerated from G.2. Package manifests identify and verify their source hashes.
- Existing enclosure geometry remains compatible because component/pad/model positions, outline and mounting holes are unchanged. Original renders retain their original provenance; moved copper/vias and silkscreen are not depicted in the older Blender reference.

The earlier silkscreen-check crash came from KiCad accessing macOS display services during a board commit. Running the local KiCad check with the required access completed successfully. No manufacturing rule was weakened to obtain a pass.

These are static checks. Assembler approval of U1/U2 exposed-pad/unfilled-hole soldering and powered supply, transient, parked-current, Wi-Fi, CAN and vehicle heater tests remain outstanding. No purchase or production approval has been made.

## Sources and reproduction

`history/rev-g1-before-adi-g2.zip` preserves the G.1 source, exports, documents and packages. `apply_adi_g2.py` is a one-time migration requiring that exact PCB hash; do not rerun it on G.2. `audit_adi_g2.py` compares against the archive. See `BUILD-REPRODUCTION.md` for validation/export order.

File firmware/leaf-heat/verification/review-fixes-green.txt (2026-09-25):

control_test
PASS retry forever with bounded delay
PASS no idle CAN or boot heat replay
PASS locked commissioning rejects transmission
PASS 2013-2015 on sequence and delayed completion
PASS off cancels all outstanding on frames
PASS local heat timeout works without any Wi-Fi callback
PASS low battery blocks on but permits off
PASS TX failure aborts sequence without replays
PASS late scheduler never bursts missed heater requests
PASS authentication rejects empty or partial credentials
10 tests, 0 failures

battery_task_test
PASS low-battery Off re-arms after partial recovery and a new On
PASS uncertain On with failed wake still re-arms low-battery Off
PASS new heating session receives its own ten-second low-voltage interval
PASS rejected low-voltage and expired On requests cannot postpone Off
PASS On rejected while a sequence is busy cannot reset the low-voltage interval
PASS failed low-battery Off is attempted once per low-voltage episode
6 tests, 0 failures

can_transport_test
PASS normal arbitration losses followed by ACK succeed
PASS continuous contention is bounded and pending On is cancelled
PASS no ACK times out and leaves no pending frame
PASS bus-off aborts transmission
PASS bus-off cannot be masked by a simultaneous TX success alert
PASS transceiver is ready before first TX at 100 Hz and 1000 Hz
PASS driver installation failure leaves transceiver in standby
PASS driver start failure releases installed driver
PASS failed alert configuration cannot transmit an unmonitored frame
9 tests, 0 failures

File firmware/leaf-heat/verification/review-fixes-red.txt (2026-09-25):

control_test
PASS retry forever with bounded delay
PASS no idle CAN or boot heat replay
PASS locked commissioning rejects transmission
PASS 2013-2015 on sequence and delayed completion
PASS off cancels all outstanding on frames
PASS local heat timeout works without any Wi-Fi callback
PASS low battery blocks on but permits off
PASS TX failure aborts sequence without replays
PASS late scheduler never bursts missed heater requests
PASS authentication rejects empty or partial credentials
10 tests, 0 failures

battery_task_test
FAIL low-battery Off re-arms after partial recovery and a new On: climate_count(0x56, 34000, 40000) == 24
FAIL uncertain On with failed wake still re-arms low-battery Off: climate_count(0x56, 34000, 40000) == 24
FAIL new heating session receives its own ten-second low-voltage interval: climate_count(0x56, 0, 21000) == 0
PASS rejected low-voltage and expired On requests cannot postpone Off
PASS failed low-battery Off is attempted once per low-voltage episode
5 tests, 3 failures

can_transport_test
FAIL normal arbitration losses followed by ACK succeed: can_send(on)
PASS continuous contention is bounded and pending On is cancelled
PASS no ACK times out and leaves no pending frame
PASS bus-off aborts transmission
FAIL bus-off cannot be masked by a simultaneous TX success alert: !can_send(on)
FAIL transceiver is ready before first TX at 100 Hz and 1000 Hz: transmitted_at - enabled_at >= 30
PASS driver installation failure leaves transceiver in standby
PASS driver start failure releases installed driver
FAIL failed alert configuration cannot transmit an unmonitored frame: !can_send(on)
9 tests, 4 failures

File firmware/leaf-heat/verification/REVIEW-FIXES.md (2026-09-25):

# Firmware review fixes — 14 September 2026

These are firmware-only changes for the Rev G family, including the current G.2 board. The PCB, schematic, parts lists, supplier files and hardware manufacturing packages are unchanged. The default source still has CAN writing disabled and empty Wi-Fi credentials. Nothing was flashed.

## Fixes

1. **Low-battery protection per heating session.** The control task resets both its low-voltage timestamp and early-Off latch before each admissible On request. Admission requires CAN enabled, sufficient measured voltage, no active command sequence and an unexpired request. Reset happens before attempting the wake frames because a failed transmission still leaves an uncertain heat request in `Control`. Rejected requests cannot postpone an existing stop interval.
2. **Bounded normal CAN retries.** Single-shot mode is disabled so ordinary arbitration loss does not abort the command. The controller retries the current frame while the task waits up to 40 ms for its result. A missing ACK, timeout or terminal failure returns an error and invokes standby/driver cleanup, cancelling pending transmission. TX queue length remains zero, so no backlog of On frames can accumulate. A bus-off/failure alert takes priority over a simultaneous success alert; failed alert setup prevents transmission entirely. This is a scheduler timeout, not a guaranteed hard real-time cancellation deadline.
3. **Transceiver standby exit.** A 100 µs ROM delay replaces a 1 ms task delay that became zero ticks under the project's 100 Hz scheduler. The fitted TCAN3404's maximum standby-to-normal time is 30 µs. This wait is for standby exit; it does not replace supply-ramp or cold-start validation.

## Evidence

- Initial regression run: 10 existing tests passed; seven of 14 added tests failed on the reported defects and related CAN error handling. The captured red log predates an additional busy-request regression and a refinement of the bus-off simulation.
- Final regression run: **25 passed, zero failures** (10 core, six control-task, nine CAN-transport tests).
- The tests compile the current production task/transport functions verbatim with small SDK doubles. They verify software decisions and simulated timing, not the physical controller or bus. The control core is compiled directly.
- The default commissioning configuration and a temporary CAN-enabled configuration both compile/link for ESP32-C3 using pinned Espressif32 6.12.0 / ESP-IDF 5.5.0. The latter uses empty Wi-Fi credentials and is not a flash/release image.
- G.2 native PCB/schematic hashes and all five hardware package hashes are checked against the existing hardware manifest. No hardware regeneration is needed.

The installed ESP-IDF 5.5.0 legacy TWAI implementation maps `ss == 0` to unlimited controller retries while active, acquires a power-management lock for the driver lifetime, and clears pending transmission state on stop. The firmware's result timeout and stop/uninstall path therefore provide the software bound. ESP32-C3 frequency-switch code also updates the ROM delay calibration. [Espressif legacy TWAI documentation](https://docs.espressif.com/projects/esp-idf/en/v5.4.4/esp32c3/api-reference/peripherals/twai.html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) describes single-shot arbitration behavior; the installed 5.5.0 source was used to confirm this project's exact API implementation.

The standby timing requirement is from the [TI TCAN3404-Q1 datasheet](https://www.ti.com/lit/gpn/TCAN3404-Q1), switching characteristics §6.9 (`tMODE`, maximum 30 µs). The configured RTOS tick rate is 100 Hz, and FreeRTOS `pdMS_TO_TICKS` uses integer division.

## Remaining bench checks

Before vehicle transmission, use an isolated bench CAN setup with correct termination and another ACK-capable node:

- Measure STB falling edge to first TXD activity; confirm at least 30 µs on each standby exit.
- Introduce competing traffic and verify a request succeeds after arbitration loss. Remove ACK / induce a bus fault and verify bounded abort, standby return and no delayed On replay.
- Exercise two heat requests with supply recovery only to about 12.3 V between them, then a drop below 12.2 V. Check a fresh approximately ten-second low-voltage interval and early Off for each request. Repeat with a failed wake transmission. Values are measured after D1 and require ADC calibration.
- Retain the hardware guide's supply, cutoff, current-draw and wiring checks. Confirm real heater behavior beside the car after commissioning.

Compilation and these simulations cannot establish physical timing, RF availability, current draw, vehicle acceptance or successful heater shutdown. Wi-Fi behavior and the independent hardware battery cutoff are unchanged.

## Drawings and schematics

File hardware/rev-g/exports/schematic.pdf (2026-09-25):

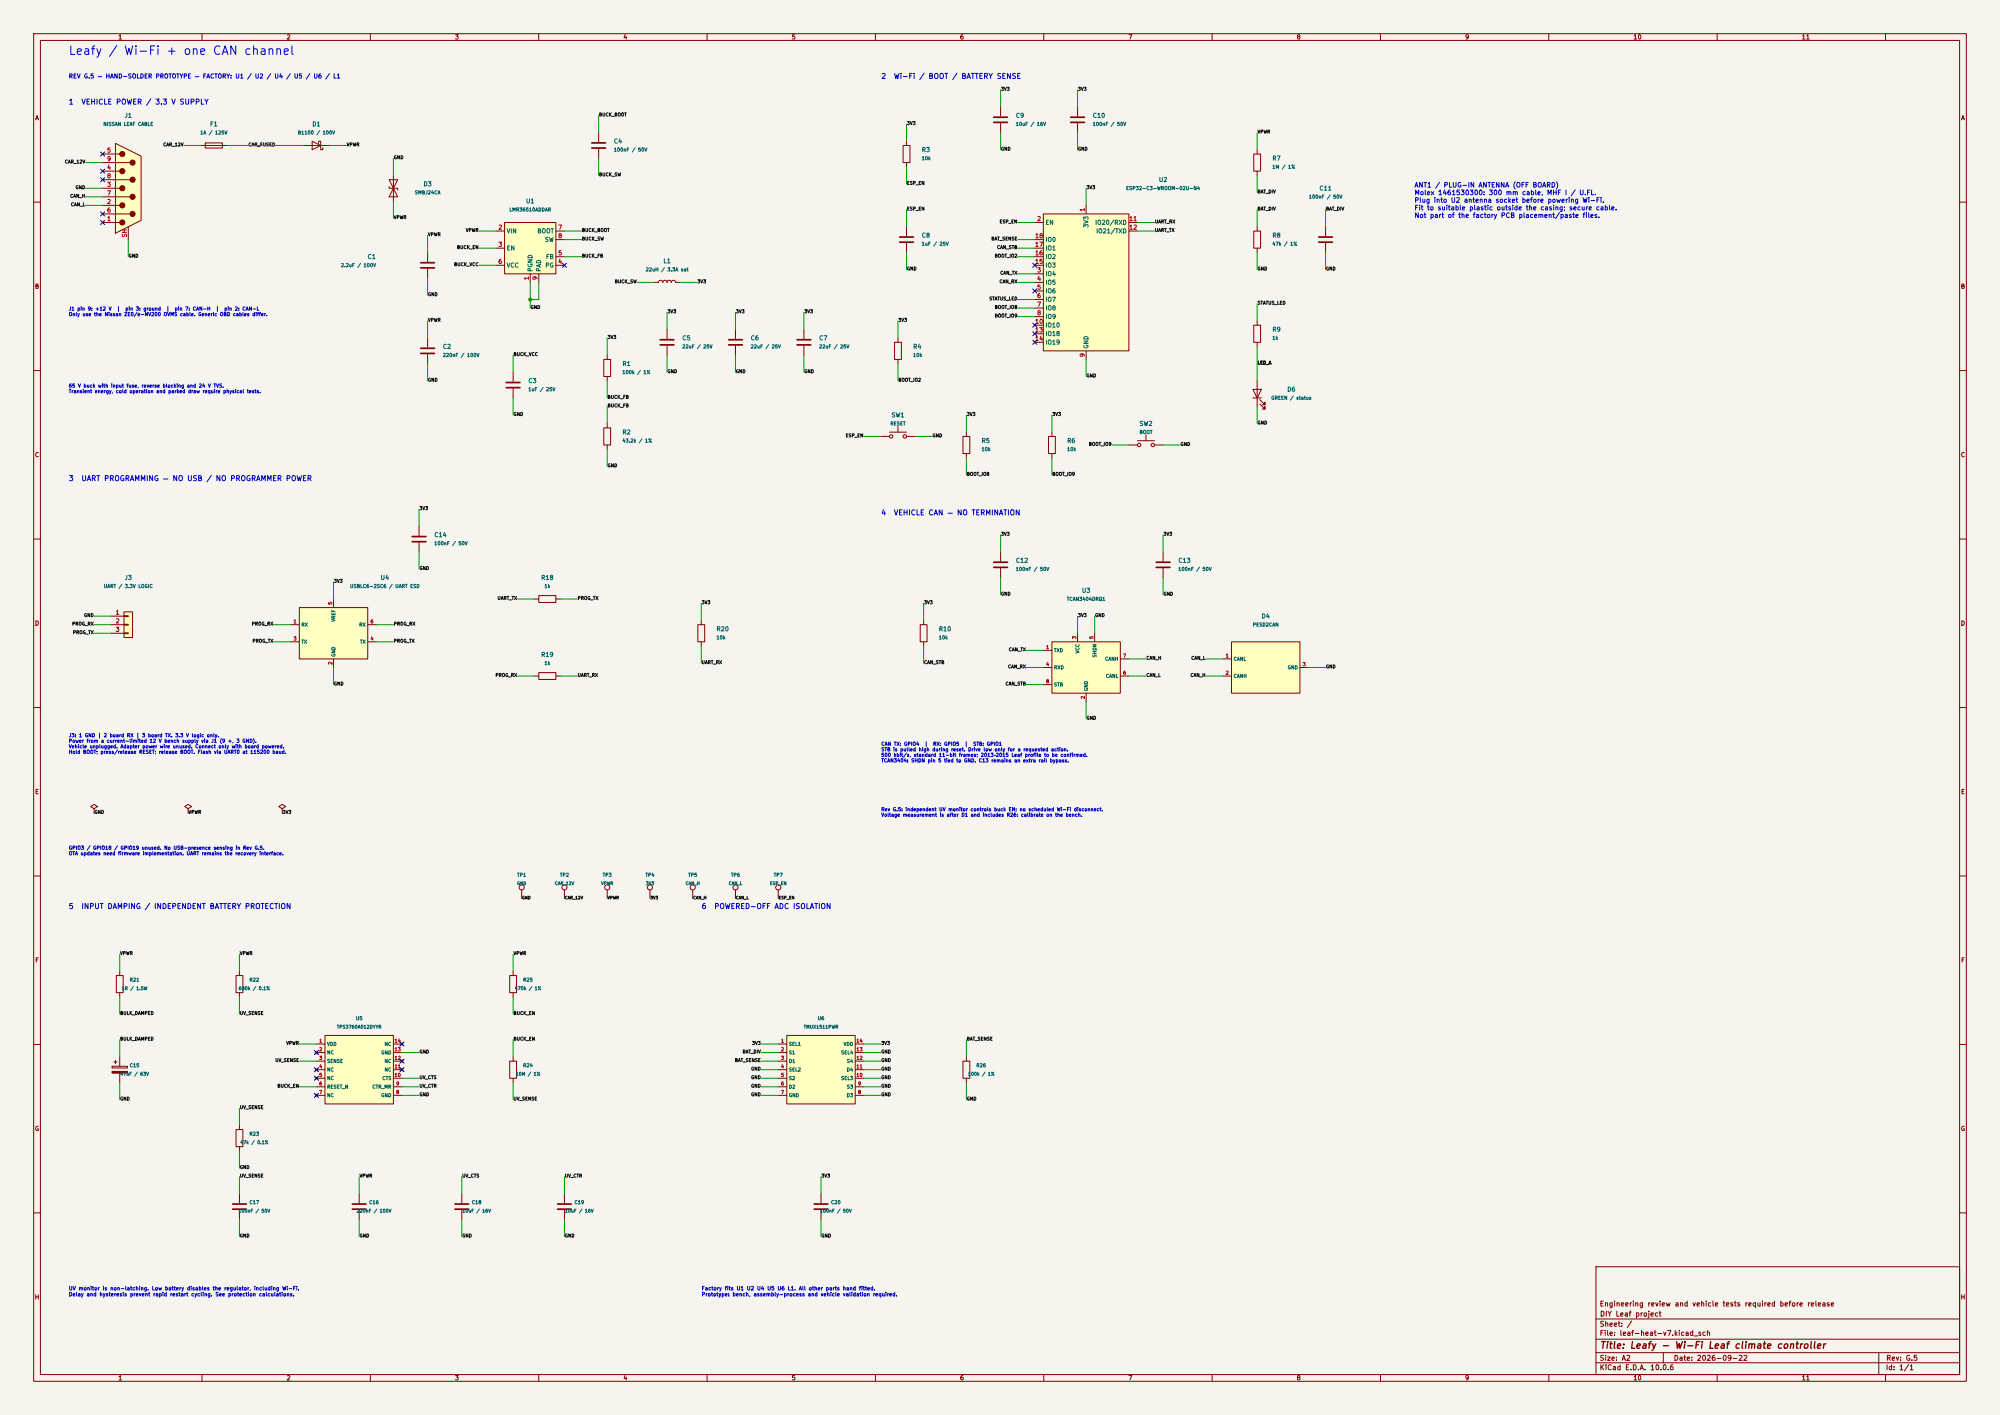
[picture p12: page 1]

REV G.5 — HAND-SOLDER PROTOTYPE — FACTORY: U1 / U2 / U4 / U5 / U6 / L1 Leafy / Wi-Fi + one CAN channel

2 Wi-Fi / BOOT / BATTERY SENSE

ANT1 / PLUG-IN ANTENNA (OFF BOARD) Molex 1461530300: 300 mm cable, MHF I / U.FL. Plug into U2 antenna socket before powering Wi-Fi. Fit to suitable plastic outside the casing; secure cable. Not part of the factory PCB placement/paste files.

J1 pin 9: +12 V | pin 3: ground | pin 7: CAN-H | pin 2: CAN-L Only use the Nissan ZE0/e-NV200 OVMS cable. Generic OBD cables differ.

65 V buck with input fuse, reverse blocking and 24 V TVS. Transient energy, cold operation and parked draw require physical tests.

PROG_RX 3 UART PROGRAMMING — NO USB / NO PROGRAMMER POWER

STB is pulled high during reset. Drive low only for a requested action. 500 kbit/s, standard 11-bit frames; 2013–2015 Leaf profile to be confirmed. TCAN3404: SHDN pin 5 tied to GND. C13 remains an extra rail bypass. Rev G.5: independent UV monitor controls buck EN; no scheduled Wi-Fi disconnect. Voltage measurement is after D1 and includes R26: calibrate on the bench. 4 VEHICLE CAN — NO TERMINATION

J3: 1 GND | 2 board RX | 3 board TX. 3.3 V logic only. Power from a current-limited 12 V bench supply via J1 (9 +, 3 GND). Vehicle unplugged. Adapter power wire unused. Connect only with board powered. Hold BOOT; press/release RESET; release BOOT. Flash via UART0 at 115200 baud.

CAN TX: GPIO4 | RX: GPIO5 | STB: GPIO1

GPIO3 / GPIO18 / GPIO19 unused. No USB-presence sensing in Rev G.5. OTA updates need firmware implementation. UART remains the recovery interface.

CAN_H
6 POWERED-OFF ADC ISOLATION

5 INPUT DAMPING / INDEPENDENT BATTERY PROTECTION

UV monitor is non-latching. Low battery disables the regulator, including Wi-Fi. Delay and hysteresis prevent rapid restart cycling. See protection calculations.

Factory fits U1 U2 U4 U5 U6 L1. All other parts hand fitted. Prototype: bench, assembly-process and vehicle validation required.

Engineering review and vehicle tests required before release
DIY Leaf project
Sheet: /
File: leaf-heat-v7.kicad_sch
Title: Leafy - Wi-Fi Leaf climate controller

Size: A2 | Rev: G.5
KiCad E.D.A. 10.0.6 | Id: 1/1

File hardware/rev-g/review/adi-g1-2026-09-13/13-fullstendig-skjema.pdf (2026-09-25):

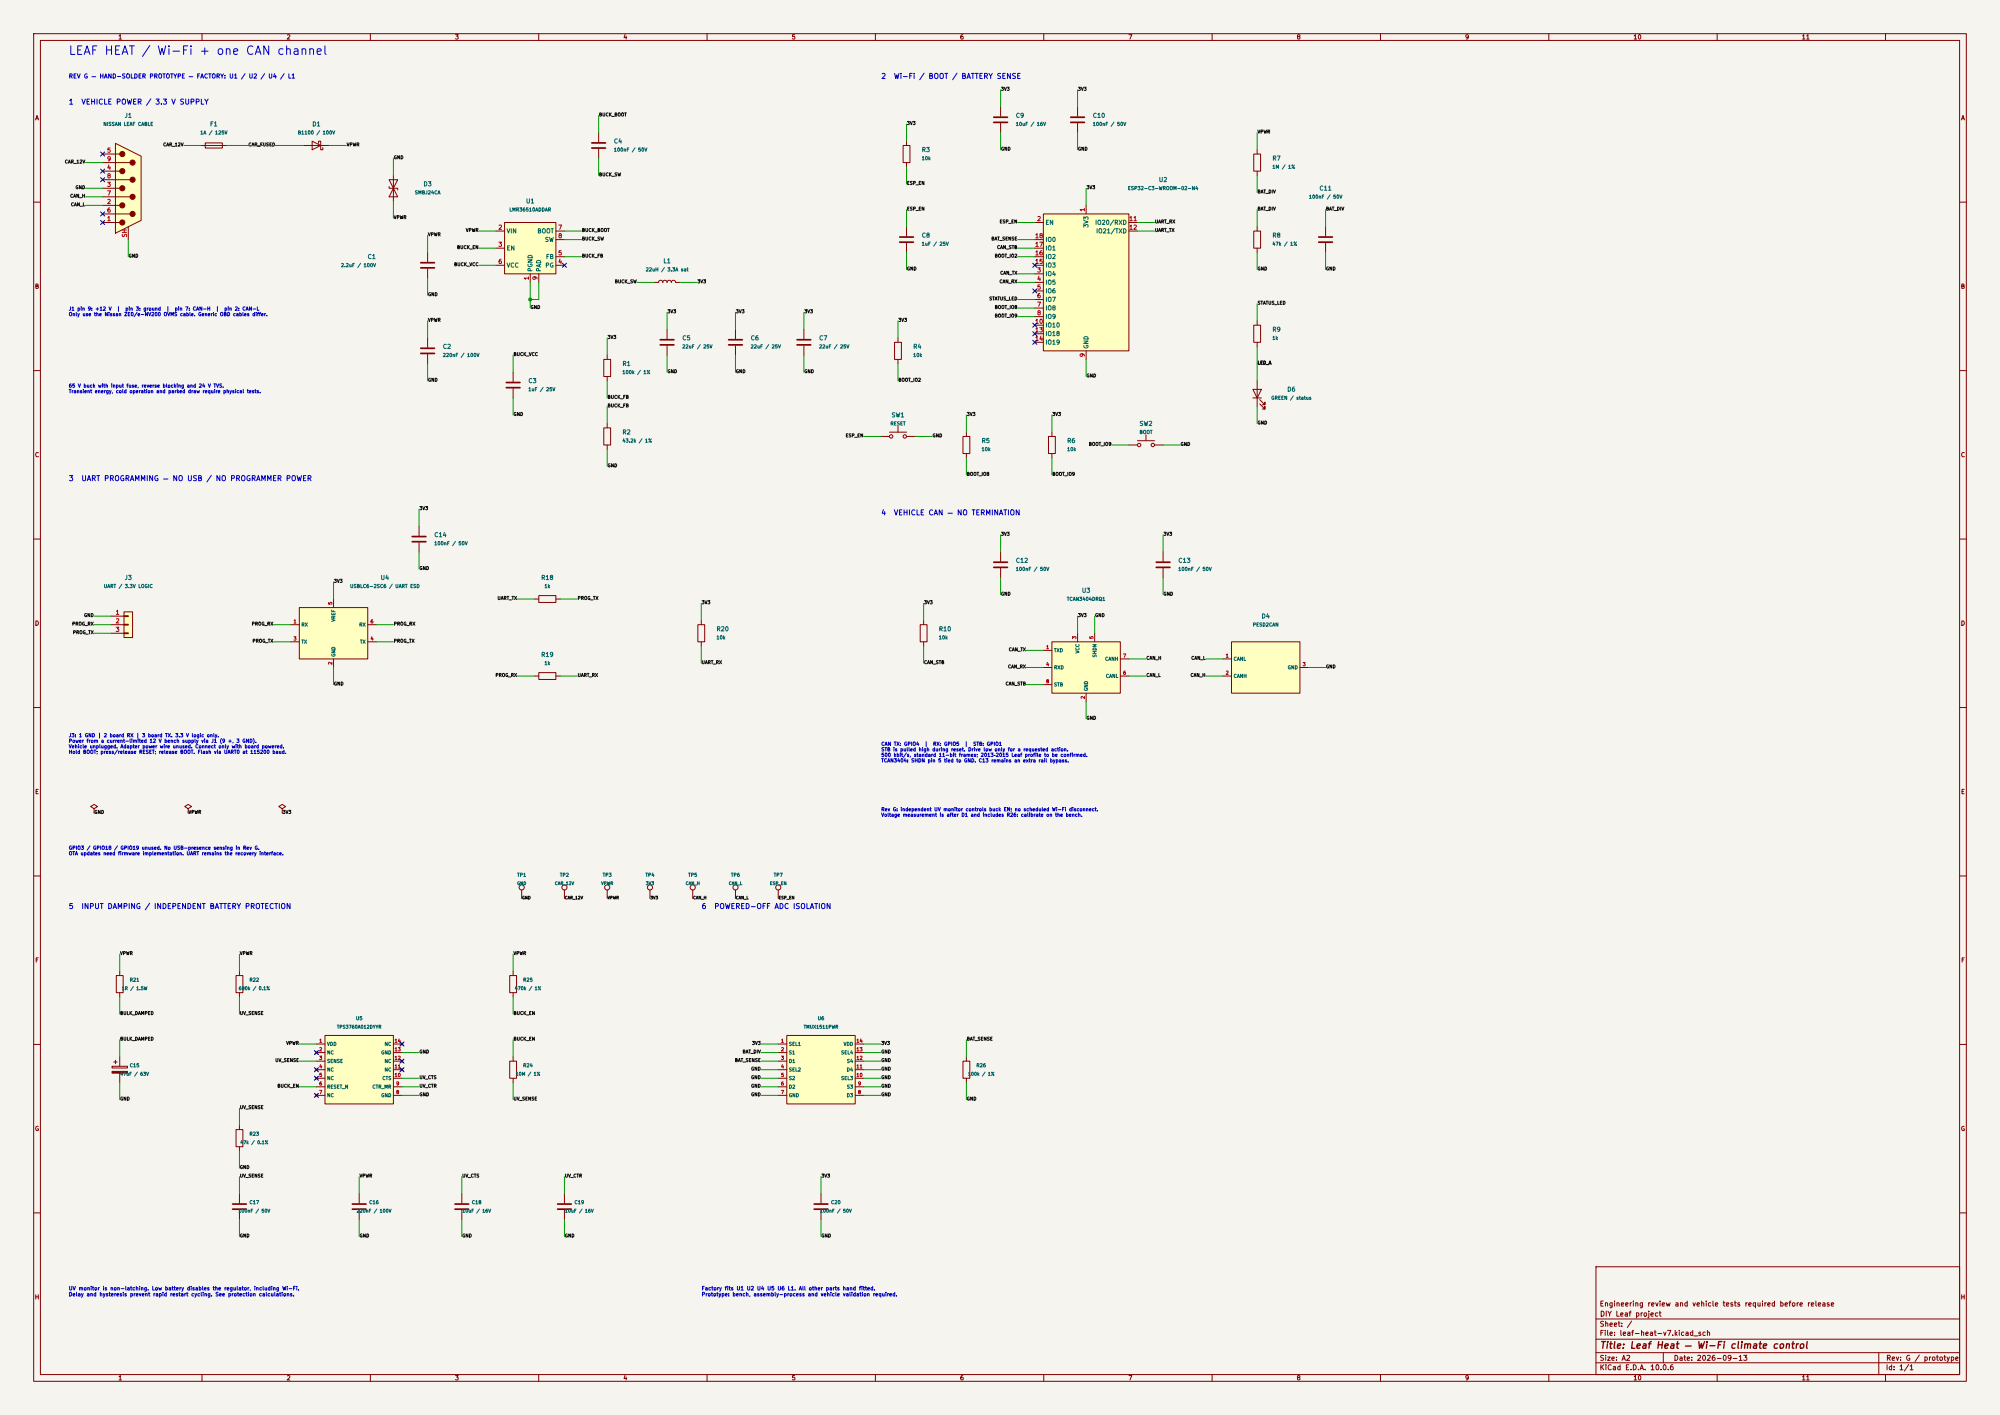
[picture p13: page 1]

J1 pin 9: +12 V | pin 3: ground | pin 7: CAN-H | pin 2: CAN-L Only use the Nissan ZE0/e-NV200 OVMS cable. Generic OBD cables differ. LEAF HEAT / Wi-Fi + one CAN channel

REV G — HAND-SOLDER PROTOTYPE — FACTORY: U1 / U2 / U4 / L1

2 Wi-Fi / BOOT / BATTERY SENSE

65 V buck with input fuse, reverse blocking and 24 V TVS. Transient energy, cold operation and parked draw require physical tests. 3 UART PROGRAMMING — NO USB / NO PROGRAMMER POWER

4 VEHICLE CAN — NO TERMINATION

CAN TX: GPIO4 | RX: GPIO5 | STB: GPIO1

STB is pulled high during reset. Drive low only for a requested action. 500 kbit/s, standard 11-bit frames; 2013–2015 Leaf profile to be confirmed. TCAN3404: SHDN pin 5 tied to GND. C13 remains an extra rail bypass. 5 INPUT DAMPING / INDEPENDENT BATTERY PROTECTION

Rev G: independent UV monitor controls buck EN; no scheduled Wi-Fi disconnect. Voltage measurement is after D1 and includes R26: calibrate on the bench.

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

Engineering review and vehicle tests required before release
DIY Leaf project
Sheet: /
File: leaf-heat-v7.kicad_sch
Title: Leaf Heat — Wi-Fi climate control

Size: A2 | Rev: G / prototype
KiCad E.D.A. 10.0.6 | Id: 1/1

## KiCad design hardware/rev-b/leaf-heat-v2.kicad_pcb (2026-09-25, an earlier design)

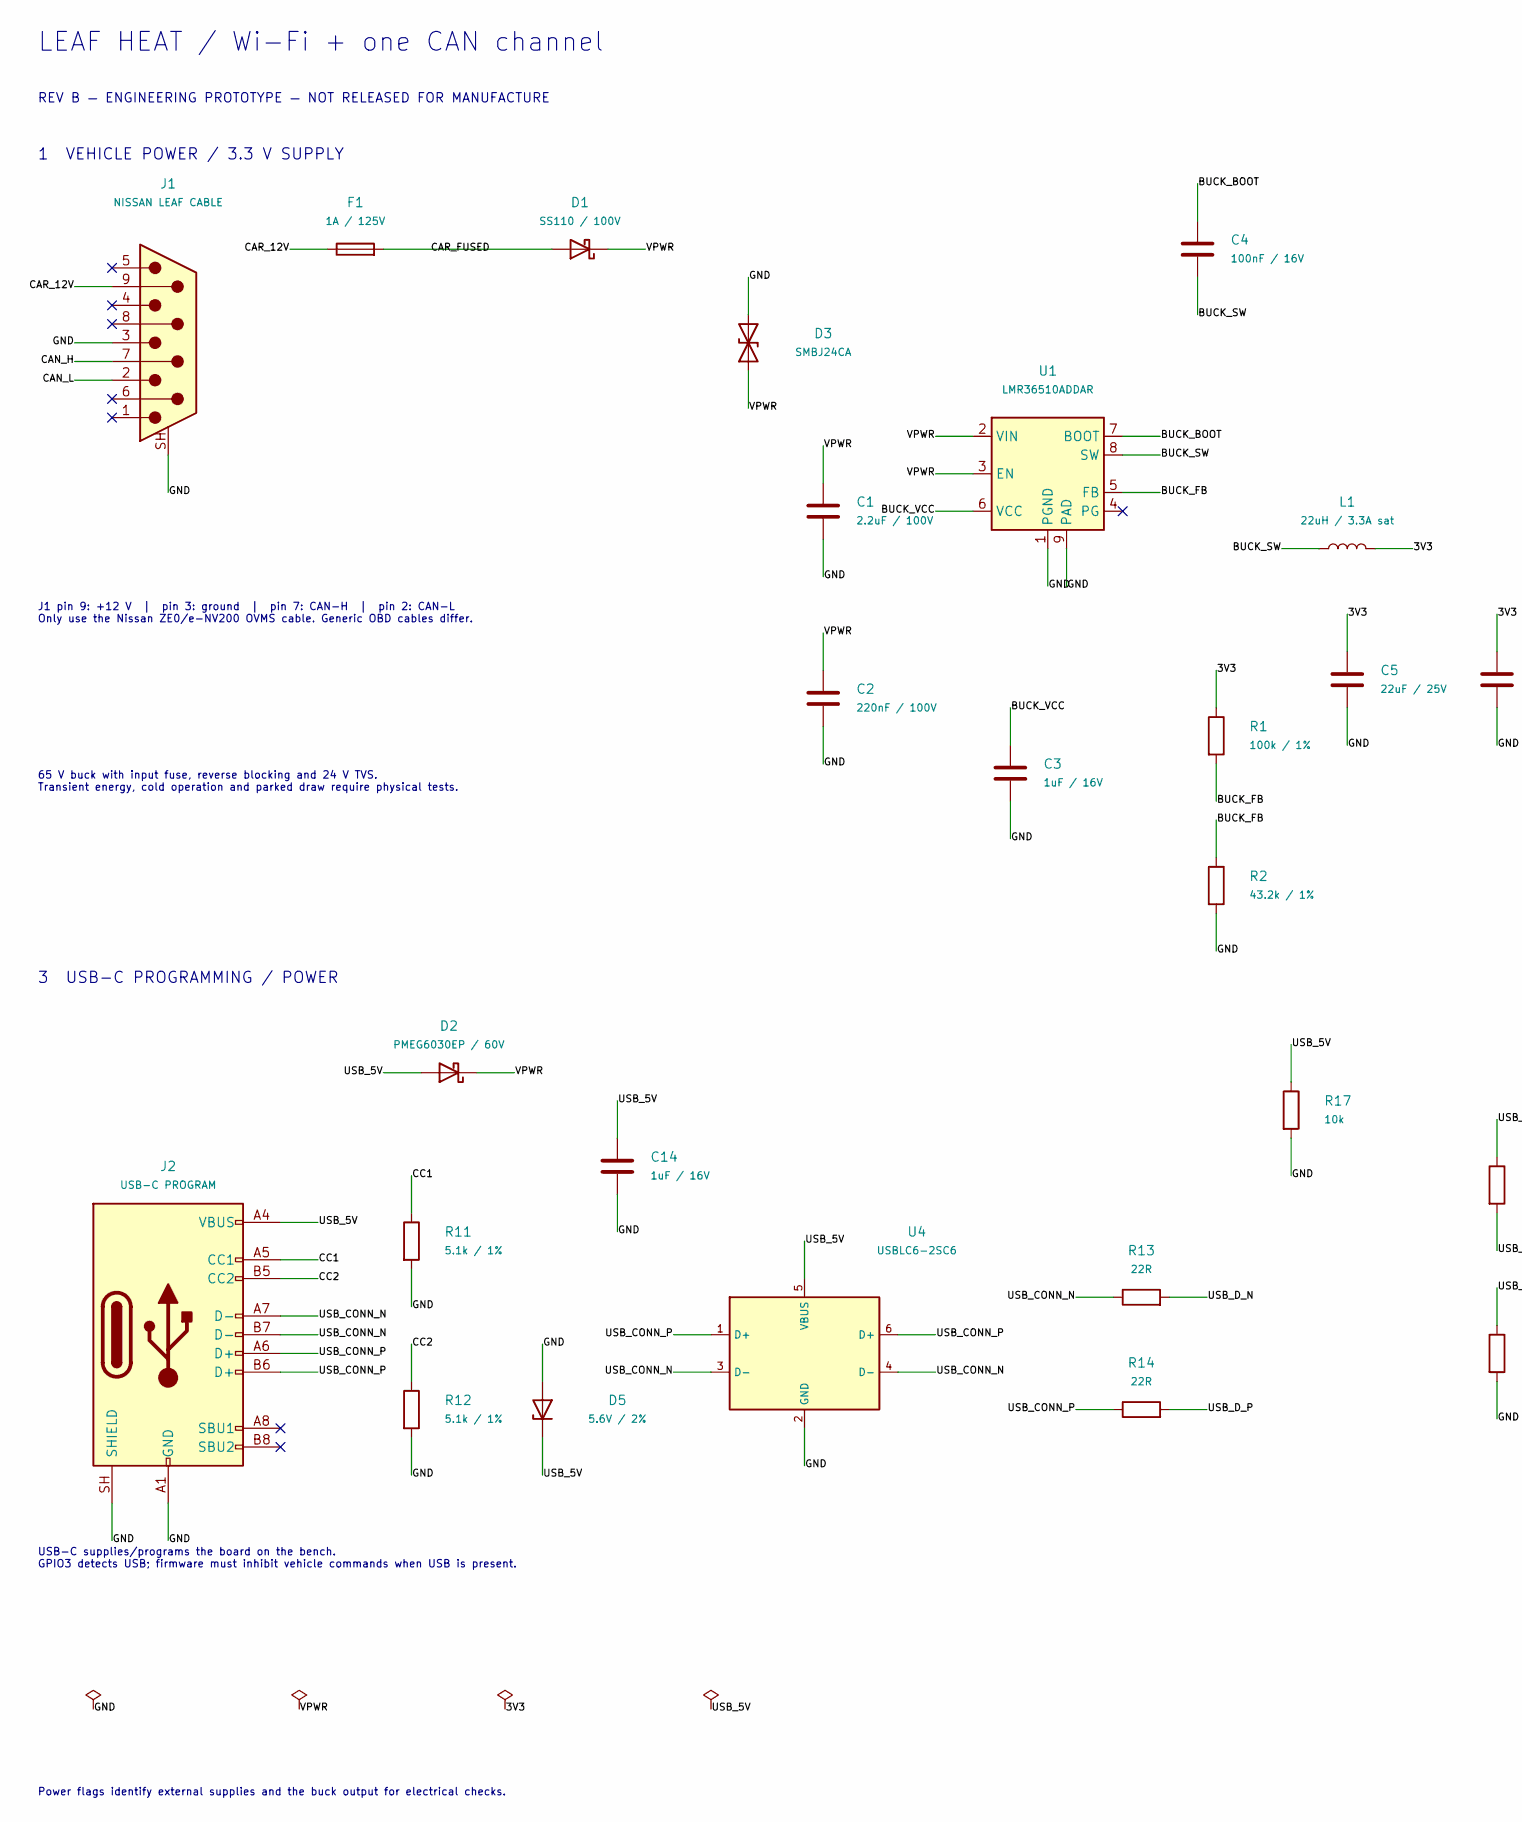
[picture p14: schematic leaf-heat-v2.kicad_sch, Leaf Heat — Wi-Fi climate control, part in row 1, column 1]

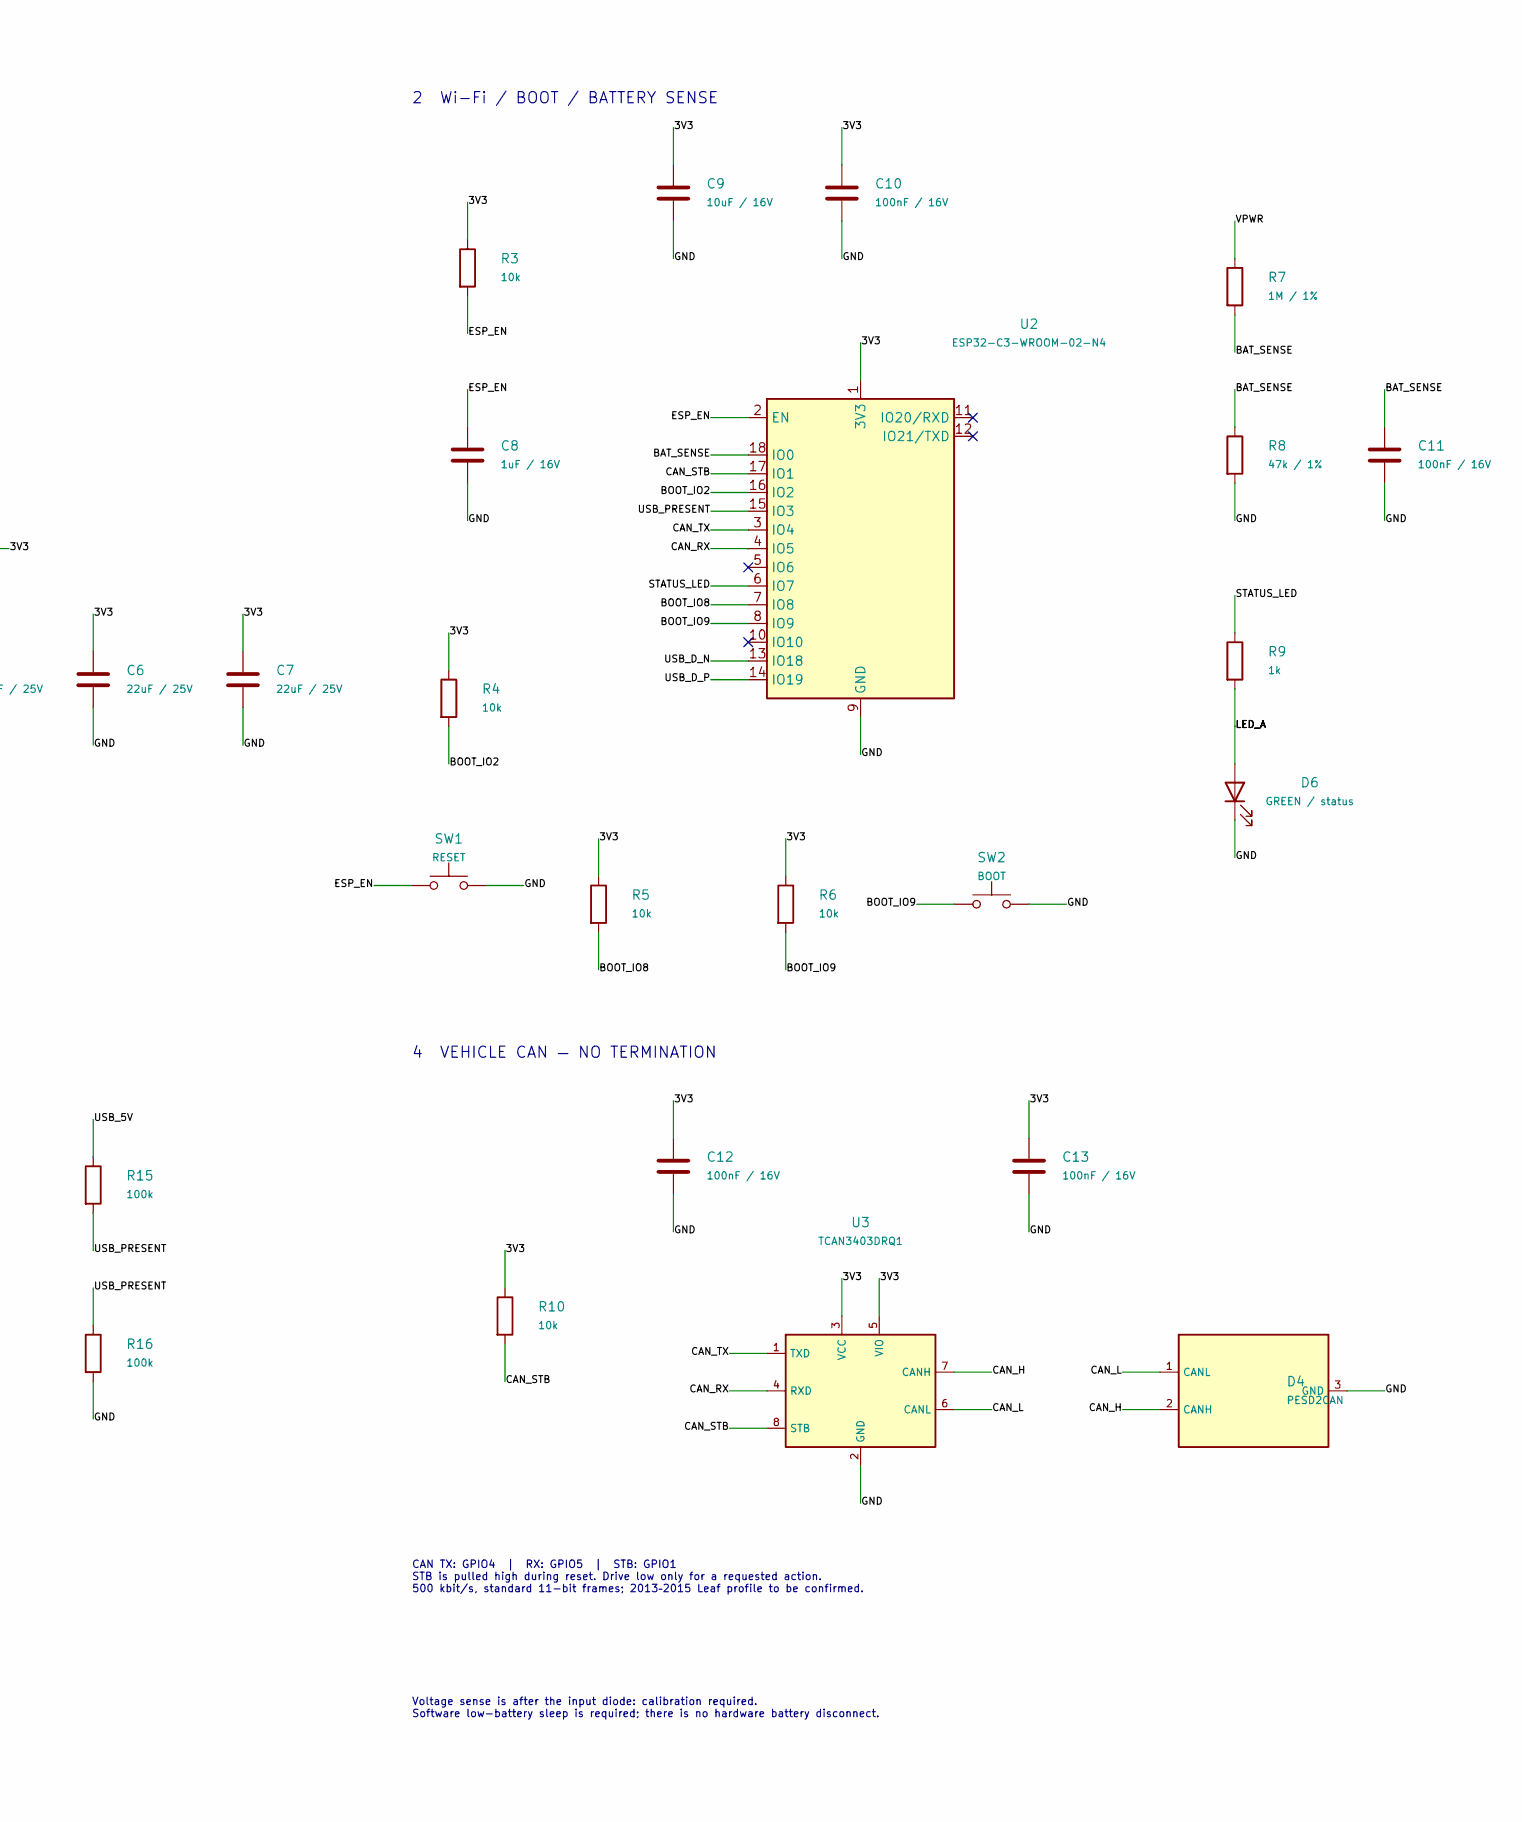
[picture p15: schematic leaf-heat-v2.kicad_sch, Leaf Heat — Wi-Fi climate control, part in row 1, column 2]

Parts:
C1: 2.2uF / 100V; C_1210_3225Metric; MPN GRM32ER72A225KA35L
C2: 220nF / 100V; C_0805_2012Metric; MPN GRM21BR72A224KAC4L
C3, C8, C14: 1uF / 16V; C_0603_1608Metric; MPN GRM188R71C105KA12D
C4, C10, C11, C12, C13: 100nF / 16V; C_0603_1608Metric; MPN GRM188R71C104KA01D
C5, C6, C7: 22uF / 25V; C_1210_3225Metric; MPN GRM32ER71E226KE15L
C9: 10uF / 16V; C_0805_2012Metric; MPN GRM21BR71C106KE51L
D1: SS110 / 100V; D_SMA; MPN SS110-13-F
D2: PMEG6030EP / 60V; D_SOD-128; MPN PMEG6030EP,115
D3: SMBJ24CA; D_SMB; MPN SMBJ24CA
D4: PESD2CAN; SOT-23; MPN PESD2CAN,215
D5: 5.6V / 2%; D_SOD-123; MPN BZT52-B5V6X
D6: GREEN / status; LED_0603_1608Metric; MPN LTST-C190KGKT
F1: 1A / 125V; Fuse_Littelfuse-NANO2-451_453; MPN 0451001.MRL
J1: NISSAN LEAF CABLE; NorComp_182-009-113R531; MPN 182-009-113R531
J2: USB-C PROGRAM; USB_C_Receptacle_GCT_USB4105-xx-A_16P_TopMnt_Horizontal; MPN USB4105-GF-A
L1: 22uH / 3.3A sat; L_Bourns_SRN6045TA; MPN SRN6045TA-220M
R1: 100k / 1%; R_0603_1608Metric; MPN RC0603FR-07100KL
R2: 43.2k / 1%; R_0603_1608Metric; MPN RC0603FR-0743K2L
R3, R4, R5, R6, R10, R17: 10k; R_0603_1608Metric; MPN RC0603FR-0710KL
R7: 1M / 1%; R_0603_1608Metric; MPN RC0603FR-071ML
R8: 47k / 1%; R_0603_1608Metric; MPN RC0603FR-0747KL
R9: 1k; R_0603_1608Metric; MPN RC0603FR-071KL
R11, R12: 5.1k / 1%; R_0603_1608Metric; MPN RC0603FR-075K1L
R13, R14: 22R; R_0603_1608Metric; MPN RC0603FR-0722RL
R15, R16: 100k; R_0603_1608Metric; MPN RC0603FR-07100KL
SW1: RESET; SW_SPST_TL3342; MPN TL3342F160QG
SW2: BOOT; SW_SPST_TL3342; MPN TL3342F160QG
U1: LMR36510ADDAR; Texas_HTSOP-8-1EP_3.9x4.9mm_P1.27mm_EP2.95x4.9mm_Mask2.4x3.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; MPN LMR36510ADDAR
U2: ESP32-C3-WROOM-02-N4; ESP32-C3-WROOM-02_0p3mm_Vias; MPN ESP32-C3-WROOM-02-N4
U3: TCAN3403DRQ1; SOIC-8_3.9x4.9mm_P1.27mm; MPN TCAN3403DRQ1
U4: USBLC6-2SC6; SOT-23-6; MPN USBLC6-2SC6

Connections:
/3V3: C5.1, C6.1, C7.1, C9.1, C10.1, C12.1, C13.1, L1.2, R1.1, R3.1, R4.1, R5.1, R6.1, R10.1, U2.1 (3V3), U3.3 (VCC), U3.5 (VIO)
/BAT_SENSE: C11.1, R7.2, R8.1, U2.18 (IO0)
/BOOT_IO2: R4.2, U2.16 (IO2)
/BOOT_IO8: R5.2, U2.7 (IO8)
/BOOT_IO9: R6.2, SW2.1, U2.8 (IO9)
/BUCK_BOOT: C4.1, U1.7 (BOOT)
/BUCK_FB: R1.2, R2.1, U1.5 (FB)
/BUCK_SW: C4.2, L1.1, U1.8 (SW)
/BUCK_VCC: C3.1, U1.6 (VCC)
/CAN_H: D4.2 (CANH), J1.7, U3.7 (CANH)
/CAN_L: D4.1 (CANL), J1.2, U3.6 (CANL)
/CAN_RX: U2.4 (IO5), U3.4 (RXD)
/CAN_STB: R10.2, U2.17 (IO1), U3.8 (STB)
/CAN_TX: U2.3 (IO4), U3.1 (TXD)
/CAR_12V: F1.1, J1.9
/CAR_FUSED: D1.2 (A), F1.2
/CC1: J2.A5 (CC1), R11.1
/CC2: J2.B5 (CC2), R12.1
/ESP_EN: C8.1, R3.2, SW1.1, U2.2 (EN)
/GND: C1.2, C2.2, C3.2, C5.2, C6.2, C7.2, C8.2, C9.2, C10.2, C11.2, C12.2, C13.2, C14.2, D3.2 (A2), D4.3 (GND), D5.2 (A), D6.1 (K), J1.3, J1.SH (PAD), J2.A1 (GND), J2.A12 (GND), J2.B1 (GND), J2.B12 (GND), J2.SH (SHIELD), R2.2, R8.2, R11.2, R12.2, R16.2, R17.2, SW1.2, SW2.2, U1.1 (PGND), U1.9 (PAD), U2.9 (GND), U2.19 (GND), U3.2 (GND), U4.2 (GND)
/LED_A: D6.2 (A), R9.2
/STATUS_LED: R9.1, U2.6 (IO7)
/USB_5V: C14.1, D2.2 (A), D5.1 (K), J2.A4 (VBUS), J2.A9 (VBUS), J2.B4 (VBUS), J2.B9 (VBUS), R15.1, R17.1, U4.5 (VBUS)
/USB_CONN_N: J2.A7 (D-), J2.B7 (D-), R13.1, U4.3 (D-), U4.4 (D-)
/USB_CONN_P: J2.A6 (D+), J2.B6 (D+), R14.1, U4.1 (D+), U4.6 (D+)
/USB_D_N: R13.2, U2.13 (IO18)
/USB_D_P: R14.2, U2.14 (IO19)
/USB_PRESENT: R15.2, R16.1, U2.15 (IO3)
/VPWR: C1.1, C2.1, D1.1 (K), D2.1 (K), D3.1 (A1), R7.1, U1.2 (VIN), U1.3 (EN)

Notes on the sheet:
LEAF HEAT / Wi-Fi + one CAN channel
REV B — ENGINEERING PROTOTYPE — NOT RELEASED FOR MANUFACTURE
1 VEHICLE POWER / 3.3 V SUPPLY
2 Wi-Fi / BOOT / BATTERY SENSE
3 USB-C PROGRAMMING / POWER
4 VEHICLE CAN — NO TERMINATION
J1 pin 9: +12 V | pin 3: ground | pin 7: CAN-H | pin 2: CAN-L Only use the Nissan ZE0/e-NV200 OVMS cable. Generic OBD cables differ.
65 V buck with input fuse, reverse blocking and 24 V TVS. Transient energy, cold operation and parked draw require physical tests.
USB-C supplies/programs the board on the bench. GPIO3 detects USB; firmware must inhibit vehicle commands when USB is present.
CAN TX: GPIO4 | RX: GPIO5 | STB: GPIO1 STB is pulled high during reset. Drive low only for a requested action. 500 kbit/s, standard 11-bit frames; 2013–2015 Leaf profile to be confirmed.
Voltage sense is after the input diode: calibration required. Software low-battery sleep is required; there is no hardware battery disconnect.
Power flags identify external supplies and the buck output for electrical checks.

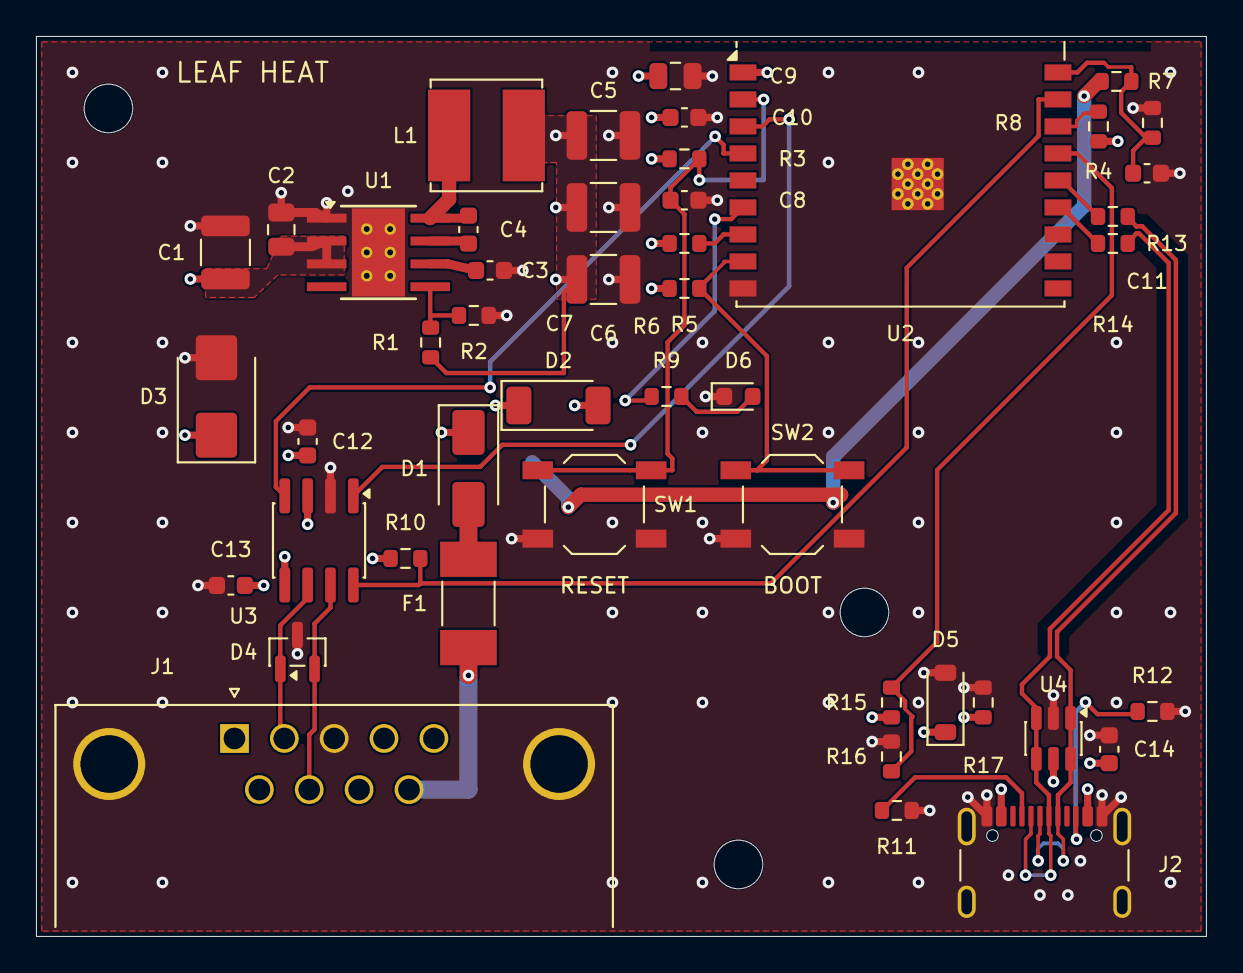
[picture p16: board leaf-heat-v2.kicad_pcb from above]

Board: 4 copper layers, 65.0 x 50.0 mm, 50 parts (0 on the bottom side), 29 nets.

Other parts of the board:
H1, H2, H3: MountingHole_2.7mm_M2.5

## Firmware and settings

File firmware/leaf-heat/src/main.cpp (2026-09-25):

#include "control.hpp"
#if __has_include("settings.hpp")
#include "settings.hpp"
#else
#include "settings.example.hpp"
#endif
#include <atomic>
#include <cstdio>
#include <cstring>
#include "freertos/FreeRTOS.h"
#include "freertos/task.h"
#include "freertos/queue.h"
#include "driver/gpio.h"
#include "driver/twai.h"
#include "esp_adc/adc_oneshot.h"
#include "esp_adc/adc_cali.h"
#include "esp_adc/adc_cali_scheme.h"
#include "esp_event.h"
#include "esp_http_server.h"
#include "esp_log.h"
#include "esp_netif.h"
#include "esp_pm.h"
#include "esp_rom_sys.h"
#include "esp_timer.h"
#include "esp_wifi.h"
#include "nvs_flash.h"

static const char* TAG="leaf";
static constexpr gpio_num_t STB=GPIO_NUM_1, TX=GPIO_NUM_4, RX=GPIO_NUM_5;
static uint64_t now_ms(){return esp_timer_get_time()/1000;}
struct Request{bool on;uint64_t expires_ms;};
static QueueHandle_t requests;
static std::atomic<bool> busy{false},heat_requested{false},battery_ok{false};
static std::atomic<int> vpwr_mv{0},last_error{0};
static bool can_started=false;
static leaf::Retry retry;
static portMUX_TYPE retry_mux=portMUX_INITIALIZER_UNLOCKED;
static std::atomic<bool> online{false};
static esp_timer_handle_t reconnect_timer;
static adc_oneshot_unit_handle_t adc;
static adc_cali_handle_t calibration=nullptr;

static void can_stop(){
 gpio_set_level(STB,1);
 if(can_started){twai_stop();twai_driver_uninstall();can_started=false;}
}
static bool can_send(const leaf::Frame& f){
 if(!LEAF_CAN_WRITE_ENABLED)return false;
 if(!can_started){
  twai_general_config_t g=TWAI_GENERAL_CONFIG_DEFAULT(TX,RX,TWAI_MODE_NORMAL);
  g.tx_queue_len=0;g.rx_queue_len=1;
  twai_timing_config_t t=TWAI_TIMING_CONFIG_500KBITS();twai_filter_config_t filter=TWAI_FILTER_CONFIG_ACCEPT_ALL();
  auto err=twai_driver_install(&g,&t,&filter);
  if(err!=ESP_OK){last_error=err;return false;}
  err=twai_start();
  if(err!=ESP_OK){twai_driver_uninstall();last_error=err;return false;}
  can_started=true;gpio_set_level(STB,0);
  // TCAN3404 standby-to-normal tMODE is at most 30 us. A tick delay can
  // round to zero; this 100 us wait also runs under the TWAI driver's PM lock.
  esp_rom_delay_us(100);
 }
 auto err=twai_reconfigure_alerts(TWAI_ALERT_TX_SUCCESS|TWAI_ALERT_TX_FAILED|TWAI_ALERT_BUS_OFF,nullptr);
 if(err!=ESP_OK){last_error=err;can_stop();return false;}
 uint32_t alerts=0;twai_read_alerts(&alerts,0);
 // Normal CAN retries handle arbitration loss. The 40 ms result wait below
 // bounds the retry window; stopping the driver cancels any pending frame.
 twai_message_t m{};m.identifier=f.id;m.data_length_code=f.size;m.ss=0;
 memcpy(m.data,f.data,f.size);
 err=twai_transmit(&m,0); // TX queue is disabled: submit directly or fail.
 if(err==ESP_OK){
  err=twai_read_alerts(&alerts,pdMS_TO_TICKS(40));
  if(err==ESP_OK&&(!(alerts&TWAI_ALERT_TX_SUCCESS)||
     (alerts&(TWAI_ALERT_TX_FAILED|TWAI_ALERT_BUS_OFF))))err=ESP_FAIL;
 }
 if(err!=ESP_OK){last_error=err;can_stop();return false;}
 return true;
}
static int read_vpwr(){
 if(!calibration)return 0;
 int total=0;
 for(int i=0;i<16;i++){
  int raw=0,mv=0;
  if(adc_oneshot_read(adc,ADC_CHANNEL_0,&raw)!=ESP_OK||adc_cali_raw_to_voltage(calibration,raw,&mv)!=ESP_OK)return 0;
  total+=mv;
 }
 return static_cast<int>((total/16.0f)*LEAF_ADC_SCALE*LEAF_ADC_CORRECTION);
}
static void control_task(void*){
 leaf::Control control(can_send);
 uint64_t sample_due=0,low_since=0;bool low_off_sent=false;
 while(true){
  auto now=now_ms();
  if(now>=sample_due){
   sample_due=now+1000;int mv=read_vpwr();vpwr_mv=mv;
   battery_ok=mv>=LEAF_MIN_HEAT_VPWR*1000;
   if(!battery_ok){
    if(!low_since)low_since=now;
    if(control.heating_requested()&&!low_off_sent&&now-low_since>=10000){
     control.request(false,now,LEAF_CAN_WRITE_ENABLED,false);low_off_sent=true;
    }
   }else if(mv>(LEAF_MIN_HEAT_VPWR+0.2f)*1000){low_since=0;low_off_sent=false;}
  }
  Request request;
  if(xQueueReceive(requests,&request,0)==pdTRUE){
   if(!request.on||now<=request.expires_ms){
    last_error=0;
    // Re-arm for every admitted On, even if its wake transmission then fails:
    // Control retains an uncertain heat request in that case. Rejected On
    // requests must not postpone the current session's low-battery shutdown.
    if(request.on&&LEAF_CAN_WRITE_ENABLED&&battery_ok&&!control.busy()){
     low_since=0;low_off_sent=false;
    }
    if(!control.request(request.on,now,LEAF_CAN_WRITE_ENABLED,battery_ok))last_error=ESP_ERR_INVALID_STATE;
   }else last_error=ESP_ERR_TIMEOUT;
  }
  control.tick(now_ms());busy=control.busy();heat_requested=control.heating_requested();
  if(!control.busy())can_stop();
  vTaskDelay(pdMS_TO_TICKS(20));
 }
}
static void schedule_reconnect(){
 if(online)return;
 portENTER_CRITICAL(&retry_mux);auto delay=retry.next_ms();portEXIT_CRITICAL(&retry_mux);
 esp_timer_stop(reconnect_timer);
 esp_timer_start_once(reconnect_timer,static_cast<uint64_t>(delay)*1000);
}
static void reconnect(void*){if(!online&&esp_wifi_connect()!=ESP_OK)schedule_reconnect();}
static void wifi_event(void*,esp_event_base_t base,int32_t id,void* data){
 if(base==WIFI_EVENT&&id==WIFI_EVENT_STA_START)reconnect(nullptr);
 else if(base==WIFI_EVENT&&id==WIFI_EVENT_STA_DISCONNECTED){online=false;schedule_reconnect();}
 else if(base==IP_EVENT&&id==IP_EVENT_STA_GOT_IP){
  online=true;esp_timer_stop(reconnect_timer);
  portENTER_CRITICAL(&retry_mux);retry.connected();portEXIT_CRITICAL(&retry_mux);
  auto* e=static_cast<ip_event_got_ip_t*>(data);
  ESP_LOGI(TAG,"Open http://" IPSTR " (reserve this address in your router)",IP2STR(&e->ip_info.ip));
 }
}
static const char PAGE[]=R"HTML(<!doctype html><html><meta name="viewport" content="width=device-width,initial-scale=1"><title>Leaf heat</title><style>body{font:18px system-ui;max-width:34em;margin:3em auto;padding:1em}button,input{font:inherit;padding:.7em;margin:.3em}pre{white-space:pre-wrap}</style><h1>Leaf heat</h1><p>Connected locally. Commands do not confirm the car's actual heater state.</p><input id="key" type="password" placeholder="Control key" autocomplete="off"><p><button onclick="command('on')">Heat on</button><button onclick="command('off')">Heat off</button></p><p id="result"></p><pre id="status"></pre><script>
async function command(action){try{let r=await fetch('/api/'+action,{method:'POST',headers:{'X-Leaf-Key':document.getElementById('key').value}});document.getElementById('result').textContent=await r.text()}catch(e){document.getElementById('result').textContent='Connection lost. Command outcome unknown; check the car.'}}
async function refresh(){try{let r=await fetch('/api/status',{cache:'no-store'});document.getElementById('status').textContent=await r.text()}catch(e){document.getElementById('status').textContent='Device unreachable. Retrying…'}}setInterval(refresh,5000);refresh();
</script></html>)HTML";
static esp_err_t home(httpd_req_t* r){httpd_resp_set_type(r,"text/html");httpd_resp_set_hdr(r,"Cache-Control","no-store");return httpd_resp_send(r,PAGE,HTTPD_RESP_USE_STRLEN);}
static esp_err_t status(httpd_req_t*r){
 char out[360];snprintf(out,sizeof(out),"CAN controls: %s\nProtected supply: %.2f V (after input diode)\nRequest sequence: %s\nLocal heat request / timer: %s\nLast command error: %d\nActual heater state: unverified",LEAF_CAN_WRITE_ENABLED?"enabled":"locked for commissioning",vpwr_mv/1000.0,busy?"running":"idle",heat_requested?"active or outcome uncertain":"none",last_error.load());
 httpd_resp_set_hdr(r,"Cache-Control","no-store");return httpd_resp_send(r,out,HTTPD_RESP_USE_STRLEN);
}
static esp_err_t command(httpd_req_t*r){
 char key[129]{};
 auto len=httpd_req_get_hdr_value_len(r,"X-Leaf-Key");
 if(len==0||len>=sizeof(key)||httpd_req_get_hdr_value_str(r,"X-Leaf-Key",key,sizeof(key))!=ESP_OK||!leaf::authorized(key,LEAF_CONTROL_KEY)){
  httpd_resp_set_status(r,"401 Unauthorized");return httpd_resp_sendstr(r,"Control key required.");
 }
 if(r->content_len!=0)return httpd_resp_send_err(r,HTTPD_400_BAD_REQUEST,"Request body must be empty.");
 if(!LEAF_CAN_WRITE_ENABLED)return httpd_resp_send_err(r,HTTPD_403_FORBIDDEN,"CAN is locked until commissioning checks pass.");
 bool on=strcmp(r->uri,"/api/on")==0;
 if(on&&(!battery_ok||busy)){httpd_resp_set_status(r,"409 Conflict");return httpd_resp_sendstr(r,"Low/unknown battery voltage or a command is running.");}
 Request q{on,now_ms()+1000};
 // A length-one queue lets Off replace a not-yet-executed On. Never queue On behind Off.
 if(on){if(xQueueSend(requests,&q,0)!=pdTRUE){httpd_resp_set_status(r,"409 Conflict");return httpd_resp_sendstr(r,"A command is pending.");}}
 else xQueueOverwrite(requests,&q);
 httpd_resp_set_status(r,"202 Accepted");return httpd_resp_sendstr(r,"Request submitted. Verify the heater in the car.");
}
extern "C" void app_main(){
 // Standby before any network or ADC initialization. External R10 also holds standby at reset.
 gpio_set_level(STB,1);gpio_set_direction(STB,GPIO_MODE_OUTPUT);
 auto err=nvs_flash_init();
 if(err==ESP_ERR_NVS_NO_FREE_PAGES||err==ESP_ERR_NVS_NEW_VERSION_FOUND){ESP_ERROR_CHECK(nvs_flash_erase());err=nvs_flash_init();}
 ESP_ERROR_CHECK(err);
 esp_pm_config_t pm{};pm.max_freq_mhz=80;pm.min_freq_mhz=40;pm.light_sleep_enable=true;
 ESP_ERROR_CHECK(esp_pm_configure(&pm));
 adc_oneshot_unit_init_cfg_t unit{};unit.unit_id=ADC_UNIT_1;
 ESP_ERROR_CHECK(adc_oneshot_new_unit(&unit,&adc));
 adc_oneshot_chan_cfg_t ch{};ch.atten=ADC_ATTEN_DB_6;ch.bitwidth=ADC_BITWIDTH_DEFAULT;
 ESP_ERROR_CHECK(adc_oneshot_config_channel(adc,ADC_CHANNEL_0,&ch));
 adc_cali_curve_fitting_config_t cal{};cal.unit_id=ADC_UNIT_1;cal.chan=ADC_CHANNEL_0;cal.atten=ADC_ATTEN_DB_6;cal.bitwidth=ADC_BITWIDTH_DEFAULT;
 if(adc_cali_create_scheme_curve_fitting(&cal,&calibration)!=ESP_OK){calibration=nullptr;ESP_LOGE(TAG,"ADC calibration unavailable: Heat on remains blocked");}
 requests=xQueueCreate(1,sizeof(Request));assert(requests);
 xTaskCreate(control_task,"leaf_control",4096,nullptr,5,nullptr);
 ESP_ERROR_CHECK(esp_netif_init());ESP_ERROR_CHECK(esp_event_loop_create_default());
 auto* sta=esp_netif_create_default_wifi_sta();ESP_ERROR_CHECK(esp_netif_set_hostname(sta,"leaf-heat"));
 esp_timer_create_args_t timer{};timer.callback=reconnect;timer.name="wifi_retry";ESP_ERROR_CHECK(esp_timer_create(&timer,&reconnect_timer));
 ESP_ERROR_CHECK(esp_event_handler_register(WIFI_EVENT,ESP_EVENT_ANY_ID,wifi_event,nullptr));
 ESP_ERROR_CHECK(esp_event_handler_register(IP_EVENT,IP_EVENT_STA_GOT_IP,wifi_event,nullptr));
 wifi_init_config_t init=WIFI_INIT_CONFIG_DEFAULT();ESP_ERROR_CHECK(esp_wifi_init(&init));
 ESP_ERROR_CHECK(esp_wifi_set_storage(WIFI_STORAGE_RAM));ESP_ERROR_CHECK(esp_wifi_set_mode(WIFI_MODE_STA));
 wifi_config_t cfg{};
 static_assert(sizeof(LEAF_WIFI_SSID)<=sizeof(cfg.sta.ssid),"SSID too long");
 static_assert(sizeof(LEAF_WIFI_PASSWORD)<=sizeof(cfg.sta.password),"Wi-Fi password too long");
 strncpy(reinterpret_cast<char*>(cfg.sta.ssid),LEAF_WIFI_SSID,sizeof(cfg.sta.ssid));
 strncpy(reinterpret_cast<char*>(cfg.sta.password),LEAF_WIFI_PASSWORD,sizeof(cfg.sta.password));
 cfg.sta.threshold.authmode=WIFI_AUTH_WPA2_PSK;
 ESP_ERROR_CHECK(esp_wifi_set_config(WIFI_IF_STA,&cfg));
 ESP_ERROR_CHECK(esp_wifi_set_ps(WIFI_PS_MIN_MODEM));
 if(strlen(LEAF_WIFI_SSID)>0)ESP_ERROR_CHECK(esp_wifi_start());
 else ESP_LOGW(TAG,"Build with local settings.hpp to join home Wi-Fi; CAN is locked by default");
 httpd_config_t http=HTTPD_DEFAULT_CONFIG();http.lru_purge_enable=true;httpd_handle_t server;
 ESP_ERROR_CHECK(httpd_start(&server,&http));
 httpd_uri_t routes[]={{"/",HTTP_GET,home,nullptr},{"/api/status",HTTP_GET,status,nullptr},{"/api/on",HTTP_POST,command,nullptr},{"/api/off",HTTP_POST,command,nullptr}};
 for(auto& route:routes)ESP_ERROR_CHECK(httpd_register_uri_handler(server,&route));
}

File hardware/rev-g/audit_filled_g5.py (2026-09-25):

"""Release checks for Leafy G.5 against the preserved, received-parts G.4 design.

Native geometry and plotted mask/paste are checked separately. Gerbers cannot
prove physical resin filling: the supplier must implement the process notes.
"""
from pathlib import Path
import collections, copy, csv, hashlib, json, sys, zipfile
import xml.etree.ElementTree as ET
import sexpdata as sx
from gerbonara import GerberFile
from gerbonara.utils import MM
from shapely.geometry import Point, Polygon, box, GeometryCollection
from shapely.affinity import rotate

H = Path(__file__).resolve().parent
E = H / 'exports'
F = E / 'fabrication'
sha = lambda p: hashlib.sha256(p.read_bytes()).hexdigest()
def key(q): return str(q[0]) if isinstance(q, list) and q else ''
def items(q, k): return [v for v in q if key(v) == k]
def child(q, k): return next(v for v in q if key(v) == k)
def prop(q, k): return next(v[2] for v in items(q, 'property') if v[1] == k)
def bag(q, ks): return collections.Counter(sx.dumps(v) for v in q if key(v) in ks)
def copper_pads(fp):
    result = []
    for pad in items(fp, 'pad'):
        copper = [v for v in child(pad, 'layers')[1:] if v.endswith('.Cu')]
        if not copper and pad[2] != sx.Symbol('np_thru_hole'): continue
        q = copy.deepcopy(pad)
        child(q, 'layers')[:] = [sx.Symbol('layers'), *copper]
        q = [v for v in q if key(v) not in {'solder_mask_margin', 'solder_paste_margin', 'solder_paste_margin_ratio'}]
        result.append(sx.dumps(q))
    return collections.Counter(result)

def primitive_shape(p):
    if type(p).__name__ == 'Rectangle':
        return rotate(box(p.x-p.w/2, p.y-p.h/2, p.x+p.w/2, p.y+p.h/2), p.rotation, origin=(p.x,p.y), use_radians=True)
    if type(p).__name__ == 'Circle': return Point(p.x,p.y).buffer(p.r, resolution=64)
    if type(p).__name__ == 'ArcPoly':
        assert all(v is None for v in p.arc_centers), 'Unexpected curved mask/paste polygon'
        return Polygon(p.outline)
    raise AssertionError('Unexpected Gerber primitive: '+type(p).__name__)

def gerber_shape(path):
    result = GeometryCollection()
    for obj in GerberFile.open(path).objects:
        local = GeometryCollection()
        for prim in obj.to_primitives(unit=MM):
            shape = primitive_shape(prim)
            local = local.union(shape) if prim.polarity_dark == obj.polarity_dark else local.difference(shape)
        result = result.union(local) if obj.polarity_dark else result.difference(local)
    return result

def main():
    with zipfile.ZipFile(H/'history/rev-g4-before-filled-g5.zip') as z:
        manifest = json.loads(z.read('BASELINE-MANIFEST.json'))
        for n, digest in manifest.items(): assert hashlib.sha256(z.read(n)).hexdigest() == digest, n
        old = sx.loads(z.read('leaf-heat-v7.kicad_pcb').decode())
        board = sx.loads((H/'leaf-heat-v7.kicad_pcb').read_text())
        oldfps = {prop(f,'Reference'): f for f in items(old,'footprint')}
        fps = {prop(f,'Reference'): f for f in items(board,'footprint')}
        assert fps.keys() == oldfps.keys()
        assert bag(old, {'segment','arc','via','net','layers','zone','gr_line','gr_arc','gr_rect','setup'}) == bag(board, {'segment','arc','via','net','layers','zone','gr_line','gr_arc','gr_rect','setup'}), 'Electrical copper, drill routing, outline or stackup changed'
        for ref, fp in fps.items():
            assert bag(fp, {'at','path','model','attr'}) == bag(oldfps[ref], {'at','path','model','attr'}), ref
            assert copper_pads(fp) == copper_pads(oldfps[ref]), (ref, 'Copper/pin/drill changed')
            if ref not in {'U1','U2'}: assert fp == oldfps[ref], (ref,'Unexpected footprint change')
        oldsch = sx.loads(z.read('leaf-heat-v7.kicad_sch').decode())
        sch = sx.loads((H/'leaf-heat-v7.kicad_sch').read_text())
        assert bag(oldsch, {'wire','junction','label','global_label','no_connect'}) == bag(sch, {'wire','junction','label','global_label','no_connect'})
        parts = json.loads((H/'parts.json').read_text())
        oldparts = json.loads(z.read('parts.json'))
        assert len(parts) == len(oldparts) == 55
        for a, b in zip(oldparts, parts):
            assert {k:v for k,v in a.items() if k not in {'footprint','notes'}} == {k:v for k,v in b.items() if k not in {'footprint','notes'}}, a['ref']
        assert (H/'accessories.json').read_bytes() == z.read('accessories.json')
        for name in ['BOM-HAND.csv','MOUSER-TWO-BOARDS.csv','MOUSER-CART-WITH-SUPPLIES.csv','CPL-FACTORY-JLCPCB.csv']:
            assert (E/name).read_bytes() == z.read('exports/'+name), name

        # This intentionally fails on G.4: the central mask must now be one
        # continuous opening, with no local solder-mask tents over the holes.
        groups = [('U1','9',6,.33,(0,0),(2.71,3.4)), ('U2','19',12,.30,(.96,.2),(2.7,2.7))]
        expected_holes = []
        for ref, ep, count, drill, centre, size in groups:
            fp = fps[ref]
            masks = [p for p in items(fp,'pad') if child(p,'layers')[1:] == ['F.Mask']]
            polygons = [p for p in items(fp,'fp_poly') if child(p,'layer')[1] == 'F.Mask']
            assert len(masks) == 1 and not polygons, (ref, 'Remove fragmented G.4 mask tents; use a continuous exposed thermal pad')
            assert child(masks[0],'at')[1:3] == list(centre)
            assert child(masks[0],'size')[1:3] == list(size)
            assert child(masks[0],'solder_mask_margin')[1] == 0
            holes = [p for p in items(fp,'pad') if p[1] == ep and p[2] == sx.Symbol('thru_hole')]
            assert len(holes) == count
            fx, fy = child(fp,'at')[1:3]
            for pad in holes:
                assert child(pad,'drill')[1] == drill
                assert child(pad,'zone_connect')[1] == 2, 'Thermal heat paths must remain solid'
                x,y = child(pad,'at')[1:3]
                expected_holes.append({'Reference':ref, 'X mm':f'{fx+x:.6f}', 'Y mm':f'{100-fy-y:.6f}', 'Drill mm':f'{drill:.2f}'})
        texts = [q[1] for q in items(board,'gr_text')]
        assert any('Leafy' in t and 'REV G.5' in t for t in texts)
        assert not any('LEAF HEAT' in t.upper() for t in texts)
        assert child(child(board,'title_block'),'rev')[1] == 'G.5'
        assert child(child(sch,'title_block'),'rev')[1] == 'G.5'
        print('PASS: native electrical/mechanical/received-parts compatibility, thermal mask geometry and Leafy branding')
        if '--native-only' in sys.argv: return
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
